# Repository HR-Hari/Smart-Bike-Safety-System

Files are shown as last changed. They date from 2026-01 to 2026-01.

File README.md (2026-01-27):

# Smart Bike Safety System

A **Smart Bike Safety System** for motor bikes using a **dual-microcontroller architecture**.  
The system detects theft attempts, abnormal movement, crash events, and **rider alcohol consumption**, sends **real-time alerts with GPS location** to the owner via **GSM**, and can **remotely disable the engine** for enhanced safety and security.

## Project Overview

Motor bike theft, unsafe riding, and delayed accident response remain major challenges.  
This project presents a **smart embedded safety and anti-theft solution** using **ESP32-based controllers**, inertial sensing, alcohol detection, GPS tracking, and GSM communication.

The system is divided into:

- **Master Unit (ESP32)** – Handles GPS tracking, GSM communication, crash detection, theft response, and engine cutoff.  
- **Slave Unit (ESP32-C3 Mini)** – Dedicated to rider safety monitoring, including alcohol detection and environmental sensing.

This modular design improves **reliability, power efficiency, fault isolation, and scalability**.

## System Functionality & Working

The Smart Bike Safety System operates using a **distributed dual-controller architecture** to ensure reliable monitoring and fast response. The **ESP32 Master unit**, powered directly from the bike battery, acts as the central control node responsible for decision-making, communication, and engine control. It interfaces with a **SIM900A GSM module** for SMS alerts, a **NEO-M8N GPS module** for real-time location tracking, a **5V relay** for engine cutoff, and an **MPU6050 inertial sensor** for detecting crash events and abnormal vehicle motion.

A secondary **ESP32-C3 Mini Slave unit**, powered by a rechargeable 5V battery, focuses on **rider safety monitoring**. It continuously measures alcohol concentration using the **MQ-3 alcohol sensor** and environmental conditions using the **DHT22 temperature and humidity sensor**. The Slave unit communicates safety status data wirelessly to the Master using **ESP-NOW**, enabling low-latency and power-efficient data transfer without relying on external networks.

During operation, the system continuously evaluates inputs from both controllers. If **alcohol consumption exceeds a predefined threshold**, a **crash is detected**, or **unauthorized movement** is identified, the Master unit immediately retrieves GPS coordinates and sends an **SMS alert via GSM** to the registered user. In critical scenarios, the system activates the **engine cutoff relay**, preventing the bike from being started or continuing operation. This integrated approach ensures **theft prevention, rider safety, and rapid incident notification** in a single embedded solution.

## Objectives

- Detect unauthorized movement or theft attempts  
- Detect crash events using inertial sensing  
- Detect rider alcohol consumption before or during riding  
- Send real-time SMS alerts with GPS location  
- Remotely disable the bike engine when unsafe conditions are detected  
- Implement a low-cost, embedded IoT-based safety system  

## System Architecture
            ┌────────────────────────────┐
            │        ESP32 MASTER        │
            │─────────────────────────── │
            │ • GSM (SIM900A)            │
            │ • GPS (NEO-M8N)            │
            │ • MPU6050 (Crash Detection)│
            │ • Engine Cutoff Relay      │
            │ • Alert & Control Logic    │
            └───────────▲────────────────┘
                        │ ESP-NOW
            ┌───────────┴────────────────┐
            │       ESP32-C3 MINI SLAVE  │
            │────────────────────────────│
            │ • MQ-3 (Alcohol Detection) │
            │ • DHT22 (Temp & Humidity)  │
            │ • Rider Safety Monitoring  │
            └────────────────────────────┘

## Hardware Components

### Master Unit (ESP32)

| Component | Description |
|---|---|
| ESP32 | Main controller |
| SIM900A GSM Module | SMS alert communication |
| NEO-M8N GPS Module | Real-time location tracking |
| MPU6050 | Crash and abnormal motion detection |
| 5V Relay Module | Engine cutoff control |
| Power Source | Motor bike 12V battery (regulated) |

### Slave Unit (ESP32-C3 Mini)

| Component | Description |
|---|---|
| ESP32-C3 Mini | Secondary controller |
| MQ-3 Alcohol Sensor | Rider alcohol detection |
| DHT22 | Temperature & humidity monitoring |
| Power Source | 5V rechargeable battery |

## Schematic

Schematic

## PCB & Enclosure Design

### Master Unit PCB Design
<table>
  <tr>
    <td>
      Master PCB
    </td>
    <td>
      Master 3D view
    </td>
  </tr>
</table>

### Slave Unit PCB Design

<table>
  <tr>
    <td>
      Slave PCB
    </td>
    <td>
      Slave 3D view
    </td>
  </tr>
</table>

### Master & Slave Enclosure / Casing

> **(Insert Master and Slave casing images here)**  
> *Show how the units are enclosed and protected for installation on the bike.*

## Software & Technologies

- **Programming Language**: C / C++
- **IDE**: Arduino IDE
- **Wireless Communication**:
  - ESP-NOW (ESP32 ↔ ESP32-C3)
- **Serial Communication**:
  - UART (ESP32 ↔ GSM)
  - UART (ESP32 ↔ GPS)
- **Core Concepts**:
  - Embedded Systems
  - IoT-based Vehicle Safety
  - Sensor Interfacing
  - Real-time Event Detection
  - Power Management

## Key Features

- Theft detection through abnormal motion analysis  
- Crash detection using MPU6050  
- Alcohol detection using MQ-3 sensor  
- Environmental monitoring using DHT22  
- GPS-based real-time location sharing  
- SMS alerts via GSM (SIM900A)  
- Engine immobilization using relay  
- Dual power supply for uninterrupted operation  

## Project Structure

## Testing & Validation

- Unauthorized movement and theft detection  
- Crash detection sensitivity tuning  
- Alcohol threshold calibration  
- GSM SMS delivery reliability  
- GPS fix accuracy and response time  
- Engine cutoff activation timing  

System validated under real motor bike operating conditions.

## Future Enhancements

- Mobile application integration  
- Cloud-based real-time tracking dashboard  
- Rider authentication using BLE or RFID  
- Geofencing alerts  
- AI-based rider behavior analysis

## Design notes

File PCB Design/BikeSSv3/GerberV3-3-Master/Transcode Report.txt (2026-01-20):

   ---- Transcoding 'D:\Uni\Semestter CS2\EE356\BikeSSv3\GerberV3-3-Master\BikeSSv3-Edge_Cuts.gbr' ----   Mon Nov 10 11:22:21 2025

D10   --> D100
-----------------------------------------------------------------

   ---- Transcoding 'D:\Uni\Semestter CS2\EE356\BikeSSv3\GerberV3-3-Master\BikeSSv3-F_Cu.gbr' ----   Mon Nov 10 11:22:21 2025

D34   --> D101
D35   --> D102
D36   --> D103
-----------------------------------------------------------------

   ---- Transcoding 'D:\Uni\Semestter CS2\EE356\BikeSSv3\GerberV3-3-Master\BikeSSv3-Edge_Cuts.gbr' ----   Wed Nov 12 11:34:07 2025

D10   --> D100
-----------------------------------------------------------------

   ---- Transcoding 'D:\Uni\Semestter CS2\EE356\BikeSSv3\GerberV3-3-Master\BikeSSv3-F_Cu.gbr' ----   Wed Nov 12 11:34:07 2025

D34   --> D101
D35   --> D102
D36   --> D103
-----------------------------------------------------------------

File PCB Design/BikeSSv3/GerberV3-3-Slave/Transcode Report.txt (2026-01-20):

   ---- Transcoding 'D:\Uni\Semestter CS2\EE356\BikeSSv3\GerberV3-3-Slave\BikeSSv3-Edge_Cuts.gbr' ----   Wed Nov 12 11:39:27 2025

D10   --> D100
-----------------------------------------------------------------

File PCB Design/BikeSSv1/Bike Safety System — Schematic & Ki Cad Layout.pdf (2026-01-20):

# Bike Safety System — Schematic & KiCad Layout

This document contains a complete, ready-to-follow schematic description, BOM, power-distribution and PCB layout guidance tailored for your bike safety/security system (ESP32 + NEO‑M8N + MPU6050 + optional GSM). Use this as the source-of-truth when creating the KiCad schematic and PCB.

## 1) Design goals (short)

Single 12 V input from bike. Robust input protection against reverse polarity and transients. Primary 5 V bus from a buck converter (automotive-capable) sized for bursts.
Clean 3.3 V rail (LDO) for ESP32 + IMU + GNSS (optionally use module breakout 5→3.3V if it has low-noise regulator).
Optional dedicated GSM power handling (large reservoir caps and/or dedicated regulator). Minimize switching noise coupling into GNSS/antenna and IMU.

## 2) High-level schematic (textual — map this directly into KiCad symbols)

Connectors

J1: BAT_IN — 2-pin screw terminal (VIN+, GND)
VIN+ → protection (reverse diode / MOSFET) → TVS → bulk cap → BUCK_IN
GND → system ground
J2: ANT_GPS — u.FL or SMA depending on antenna (connect to NEO-M8N ANT pad)
J3: USB_PROG — USB-C micro B as optional programming / serial power (connect via ideal-diode OR allow USB to power 5 V bus when present)
J4: OUTPUTS — Relay/Buzzer (open-drain via transistor)
J5: SIM_PWR — if using external SIM battery connector
Power block

D1 — Reverse-protection (Schottky or ideal diode MOSFET assembly). Example footprint: SOD-128 for Schottky or MOSFET SOT-23.
TVS1 — Automotive TVS (e.g., SMAJ58A or equivalent) across VIN after D1.
C_IN — Bulk electrolytic 220 µF — 1000 µF (low ESR) at VIN.
LDO1 — OPTIONAL: 5 V input soft-start or inrush limit circuit (NTC or small series resistor + MOSFET) if huge caps present.
BUCK1 — 12 V → 5.0 V buck converter. Rating: choose module/IC capable of continuous 3 A (or rated per your GSM/ESP peaks). Add LC filter at its output: ferrite bead F1 + L1 (10–47 µH) + C_OUT (100 µF electrolytic + 10 µF tantalum + 0.1 µF MLCC).
C_5V_local — 470 µF low-ESR on 5 V bus near distribution.

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
### 3.3 V domain

LDO3V3 — Low-noise LDO (e.g., TLV70033, MIC550, or similar). Input: 5 V bus after LC filter. Provide 10 µF + 0.1 µF close to LDO in/out.
C_3V3_local — 100 µF low-ESR + MLCCs near ESP32.
3.3 V net connects to: ESP32 VCC, MPU6050 VCC, (optionally) NEO‑M8N VCC if using direct 3.3 V rather than onboard regulator.
Highest-noise device (GSM)

If using SIM800L / BG95 / etc.: either create separate regulated 4 V rail or feed from 5 V bus but: Add C_GSM: 2200 µF–4700 µF low-ESR cap right at module power pins.
Add a series sense resistor or PFET disconnect and a polyfuse (resettable) so bursts don’t pull down system.
Place GSM power/antenna connectors at the board edge, physically separated from GNSS. Controller & sensors

U1: ESP32-WROOM (or WROVER if you need PSRAM) — 3.3 V VCC. Expose EN, IO0, TX0/RX0 for programming. Add 10 k pull-ups/pull-downs per reference schematic. Add decoupling: 100 nF + 10 µF.
U2: MPU6050 — I2C (SDA, SCL) to ESP32 I2C pins. Add 2.2 k pull-ups to 3.3 V if module lacks them. Decouple with 0.1 µF + 4.7 µF.
U3: NEO‑M8N (GNSS) — UART (TX/RX) to ESP32 Serial1 (use hardware serial). Also PPS pin optional to ESP32 GPIO. Power: 3.3 V is preferred. Antenna to J2. Decouple and add LC filter close to module: ferrite bead + 10 µF + 0.1 µF.
Misc

Level translators: not needed if all are 3.3 V. If any module is 5 V tolerant only (LCD), use level shifters.
Buzzer / Relay: NPN transistor (e.g., 2N2222 or SMD equivalent) with base resistor (10 k pull-down or 100 k?), flyback diode for coils, and emitter to GND. Drive from ESP32 GPIO through base resistor (4.7k).
LEDs: status LED with 4.7k series resistor.

## 3) BOM (suggested — verify footprints)

Ref | Part | Value / Notes | Qty
J1 | Screw terminal | 2-pin, 5.08 mm pitch | 1
D1 | Schottky | 40 V, SOD-128 | 1
TVS1 | TVS | 600 W, 58 V standoff or automotive-rated | 1
C_IN | Electrolytic | 470 µF, 25 V low-ESR | 1

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
Ref | Part | Value / Notes | Qty
BUCK1 | Buck module | 5 V, 3 A (module or integrated IC + inductor) | 1
L1 | Inductor | 10–47 µH (for LC) | 1
F1 | Ferrite bead | SMD ferrite (1206 or 0805) | 1
C_OUT | Electrolytic | 220 µF, 10 V low-ESR | 1
LDO3V3 | LDO | 3.3 V low-noise LDO, SOT-223 or SOT-23 | 1
C_3V3 | MLCC | 10 µF + 0.1 µF | 2
U1 | ESP32 module | WROOM or DEVKIT footprint | 1
U2 | MPU6050 | QFN breakout or module | 1
U3 | NEO‑M8N | GNSS breakout module | 1
U4 | SIM800L | if used | 1
Q1 | NPN | SOT-23 transistor for buzzer/relay | 1
Rb | Resistors | 4.7 k, 10 k etc | several

Note: exact package choices depend on your footprint preferences for soldering (hand-solder vs reflow). I recommend through-hole for connector/screw terminals and SMD for everything else.

## 4) PCB layout plan & rules (KiCad)

Layer stackup

2-layer board is fine for this project. Use:
Top: components, routing
Bottom: ground plane + routing
Recommend at least 35 µm copper (1 oz). If you expect >2 A continuous on some traces, consider 2 oz copper or heavier.
Placement priorities

Input protection & buck: place near J1 (VIN). Keep switching components local to minimize noise loops.
Bulk caps: place right at buck input & output.
GSM module: place at board edge, keep away from GNSS and ESP32 antenna path.
GNSS module & antenna: place on board corner/edge with a keep-out area around antenna. Keep it physically distant (≥30 mm ideally) from buck and GSM.
ESP32: central, but not next to buck or GSM. Keep its antenna clear (if module has antenna).
IMU: close to ESP32 to shorten I2C traces; avoid being next to switching loops.
Test pads & headers: program pins, 5 V, 3.3 V, GND, and serial lines.

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
Grounding

Use a continuous ground plane on bottom.
Route high-current return paths directly under their supply traces when possible so the plane carries return current.- Use stitching vias if you have localized ground islands.
Avoid splitting the ground plane under the GNSS antenna area.
Trace widths (conservative recommendations)

Use these conservative widths on 1 oz copper:
Signals (I2C, UART, GPIO): 0.25 mm (10 mil)
0.5 A traces: 0.8 mm
1 A traces: 1.5 mm
2 A traces: 2.5 mm
3 A traces: 3.0–3.5 mm
For the 5 V bus feeding multiple modules, use a wide plane or multiple 3.0 mm traces in parallel. Decoupling & filtering layout

Put MLCC 0.1 µF as close as possible to each IC Vcc pin.
Place larger electrolytic/tantalum caps near the module entry points.
Place ferrite bead + LC filter components in series with the 5 V feed to GNSS and ESP32 LDO input. Thermal & mechanical

If buck IC is in SMD, provide thermal vias under its pad connected to ground plane per datasheet. Keep mounting holes and mechanical pads clear of the antenna area.

## 5) KiCad project checklist (step-by-step)

Create new project in KiCad and set board units to mm.
Create schematic sheets: PWR, CONTROLLER, SENSORS, COMM, MECH.
Add symbols and annotate. Assign footprints (SOT-23, SOT-223, 0805, 1206, etc.). Add net labels: VIN, GND, 5V_BUS, 3V3, UART1_TX, UART1_RX, I2C_SDA, I2C_SCL, PPS. Run ERC and resolve warnings.
Generate netlist and import to PCBNew.
Place components following placement priorities above.
Create ground zone filled on bottom. Set thermal relief on through-hole pads. Route high-current tracks first (5 V, VIN, GND returns). Keep them short and wide. Add decoupling and testpoints. SILK notes for antenna keep-out and orientation. DRC and Gerber generation.

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
## 6) Testing & debug suggestions

Bring up the board with a current-limited bench supply and scope on the 5 V & 3.3 V rails. Watch for droops during ESP32 Wi-Fi TX and (if present) GSM bursts.
Verify GNSS fix stability with the antenna placed in intended mounting location before sealing the enclosure.
Check temperature of buck and LDO on continuous operation.
If you see jitter in GNSS, add more LC filtering or move buck further away.

## 7) Files & footprints I recommend creating in KiCad

Footprints: 2-pin screw terminal, u.FL, SOT-23 (D1), SOT-223 (LDO), 1206/0805 (passives), 3.3 V regulator SOT-23-5 for small LDOs.
Symbols: ESP32 module symbol with nets exposed (EN, IO0, IO2, GND, 3V3, TX0, RX0).

If you want, I can now: - produce a schematic PDF / SVG layout text that you can import or copy into KiCad, or - produce a detailed KiCad component placement and routing plan (with exact footprints and grid coordinates) for an assumed board size (e.g., 60×40 mm).

Tell me which of those two you want next and I will put it into the same canvas as a follow-up file.

•

•

•
•

•

•

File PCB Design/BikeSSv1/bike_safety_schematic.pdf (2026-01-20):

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

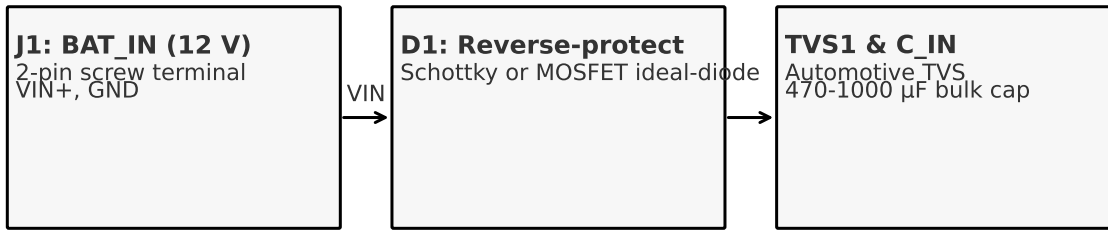
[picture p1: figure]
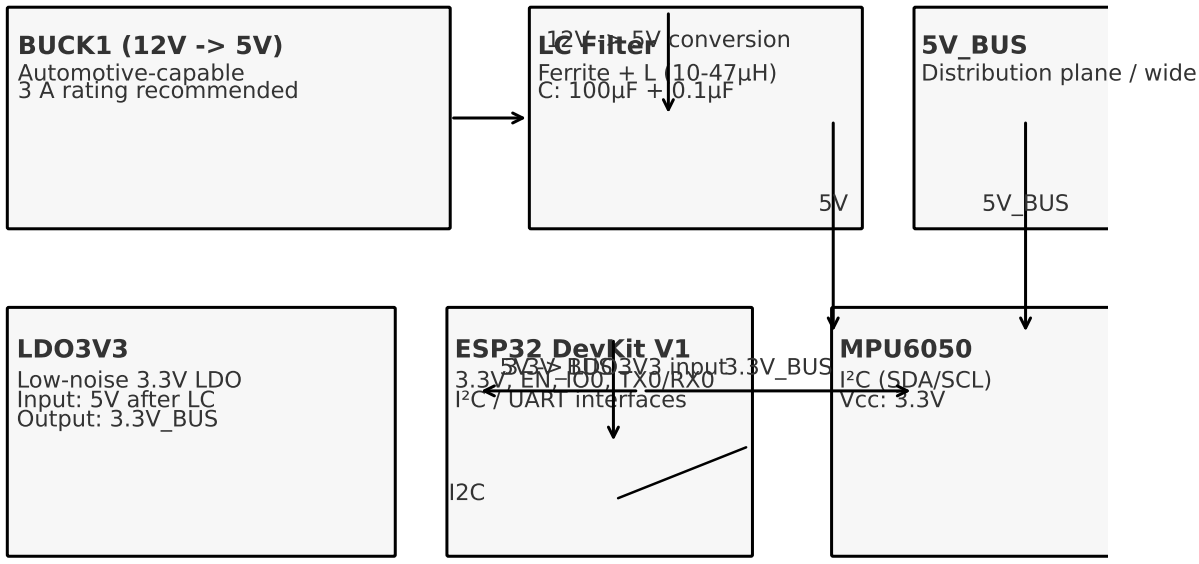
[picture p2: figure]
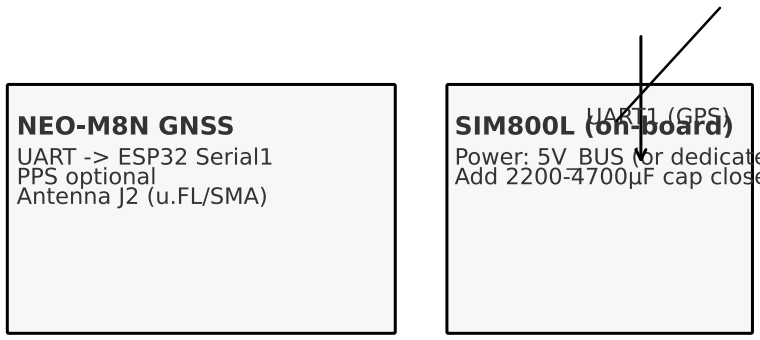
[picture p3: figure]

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

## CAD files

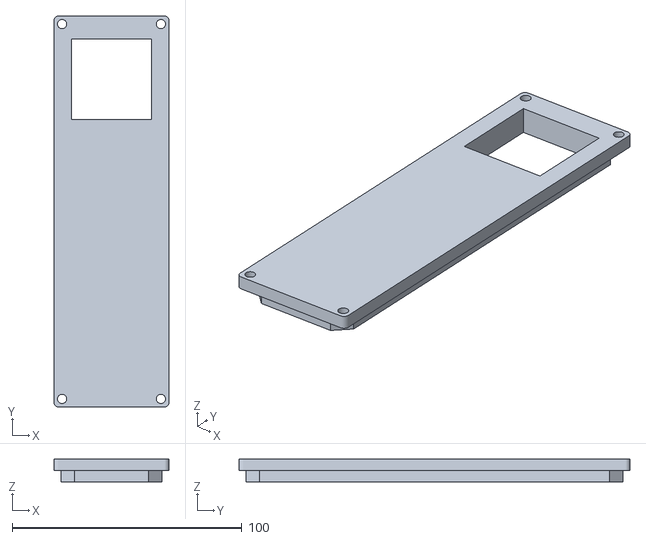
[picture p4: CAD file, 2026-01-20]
Casing/3D Print/Slave Enclosure-Lid.stl
50.0 x 170.0 x 10.0

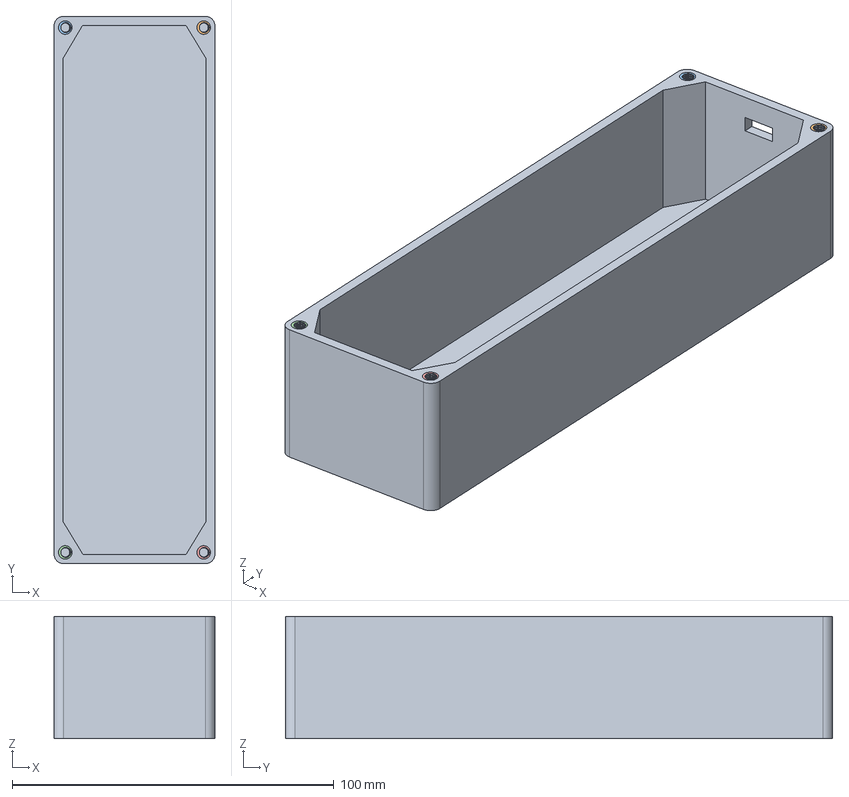
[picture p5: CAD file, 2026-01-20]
Casing/Master/Slave Big Enclosure.FCStd
50.0 x 170.0 x 38.0 mm
(M3.5)x13-ScrewDie003
(M3.5)x13-ScrewDie002
(M3.5)x13-ScrewDie001
(M3.5)x13-ScrewDie

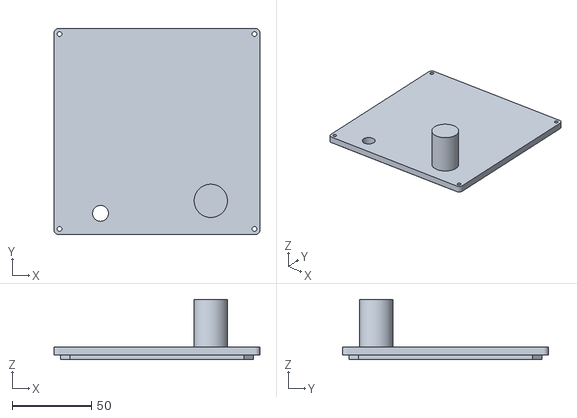
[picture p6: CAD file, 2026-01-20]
Casing/3D Print/Master Big_Enclosure-Lid -0.03.stl
130.0 x 130.0 x 38.0

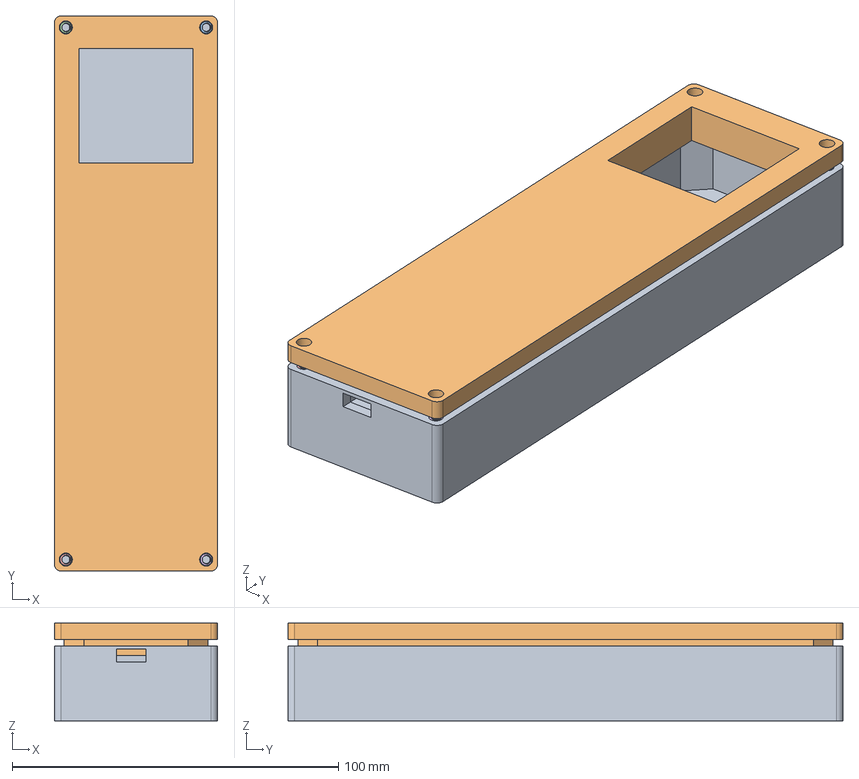
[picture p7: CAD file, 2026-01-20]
Casing/Master/Slave Enclosure.FCStd
50.0 x 170.0 x 30.0 mm
Container
Lid
M3x20-ScrewDie
M3x20-ScrewDie005
M3x20-ScrewDie004
M3x20-ScrewDie006

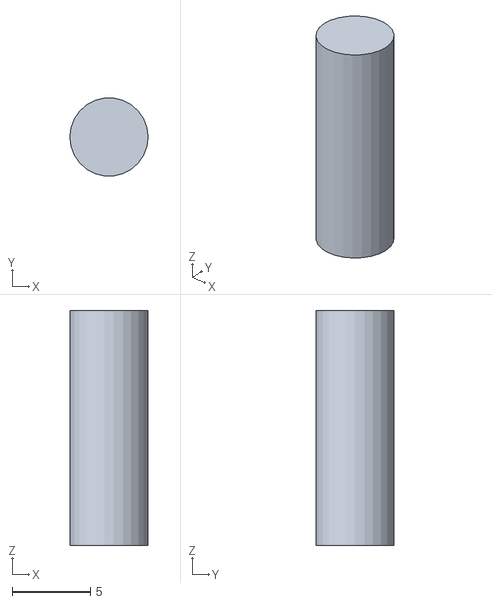
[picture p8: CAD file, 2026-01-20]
Casing/3D Print/Master Big_Enclosure-Switch.stl
5.00 x 4.96 x 15.0

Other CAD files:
Casing/3D Print/Slave Big Enclosure.stl
Casing/3D Print/Master Big_Enclosure-Lid -0.2.stl
Casing/3D Print/Master Big_Enclosure-Lid.stl

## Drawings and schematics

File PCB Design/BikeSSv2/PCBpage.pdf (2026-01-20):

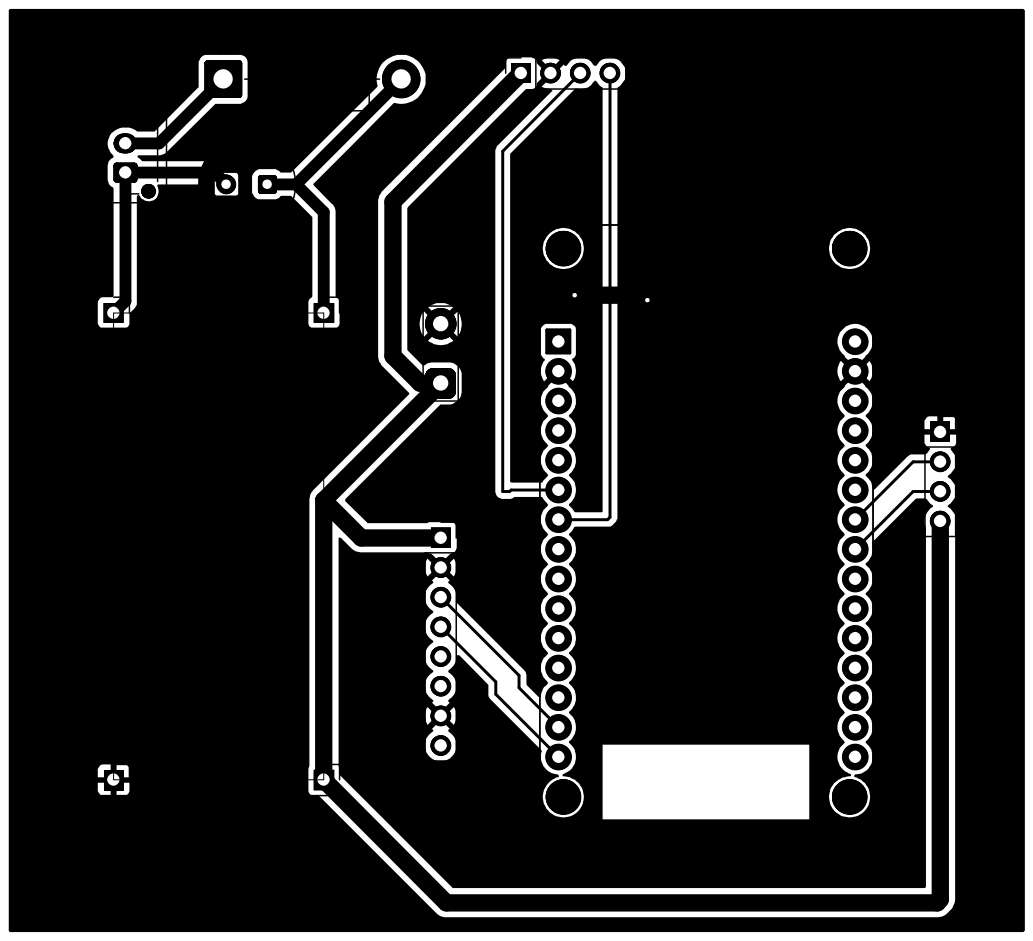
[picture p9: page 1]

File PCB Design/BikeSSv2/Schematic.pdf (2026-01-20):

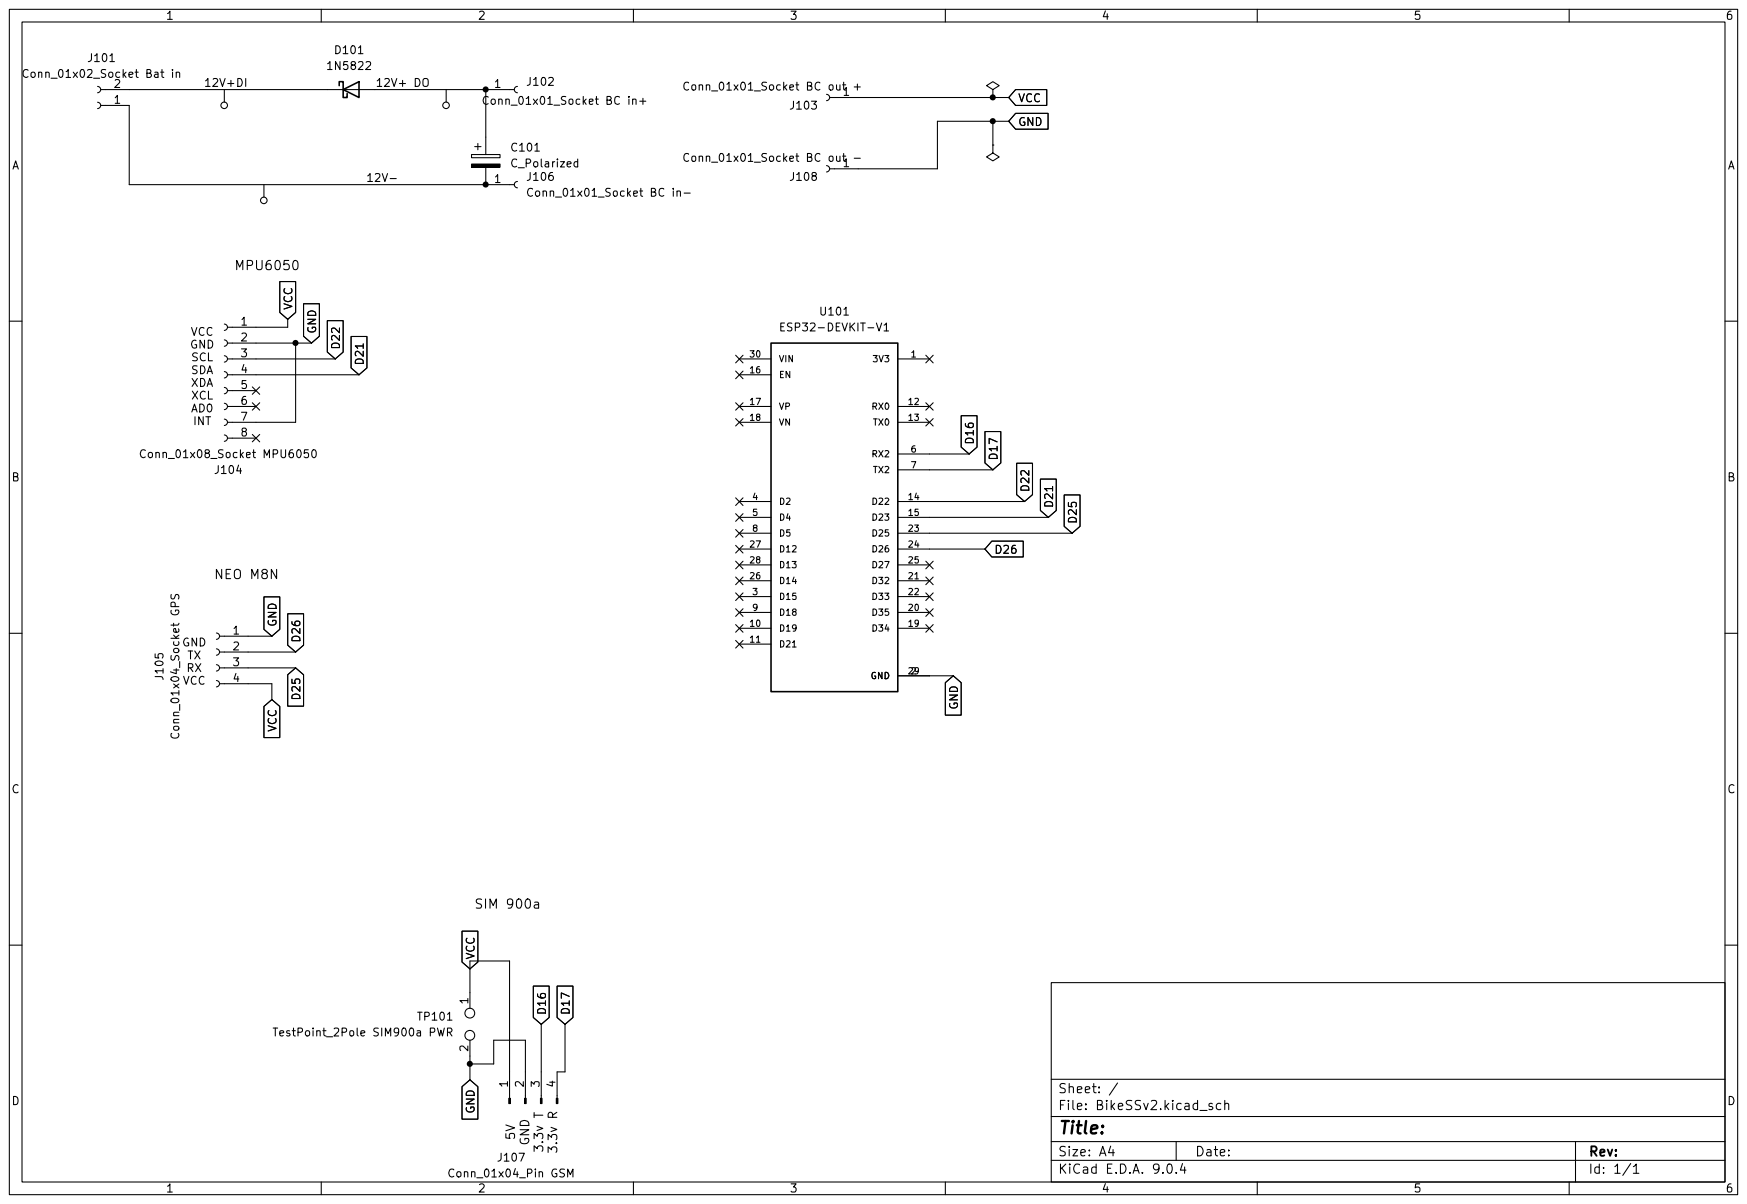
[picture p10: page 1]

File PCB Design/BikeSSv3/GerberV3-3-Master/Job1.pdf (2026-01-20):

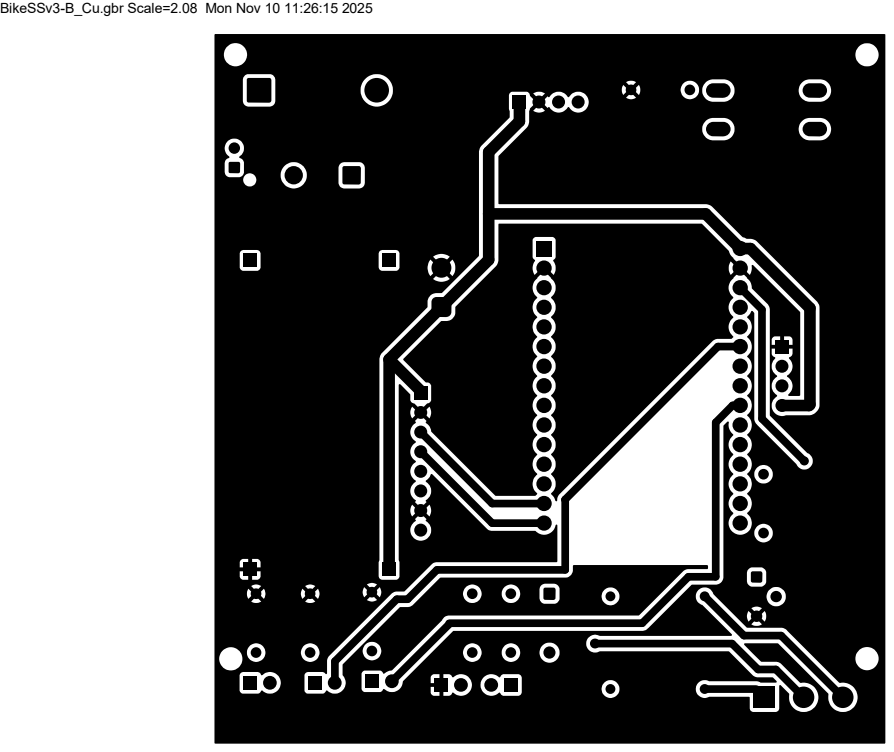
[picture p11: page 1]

BikeSSv3-B_Cu.gbr Scale=2.08 Mon Nov 10 11:26:15 2025

BikeSSv3-Edge_Cuts.gbr Scale=2.08 Mon Nov 10 11:26:15 2025

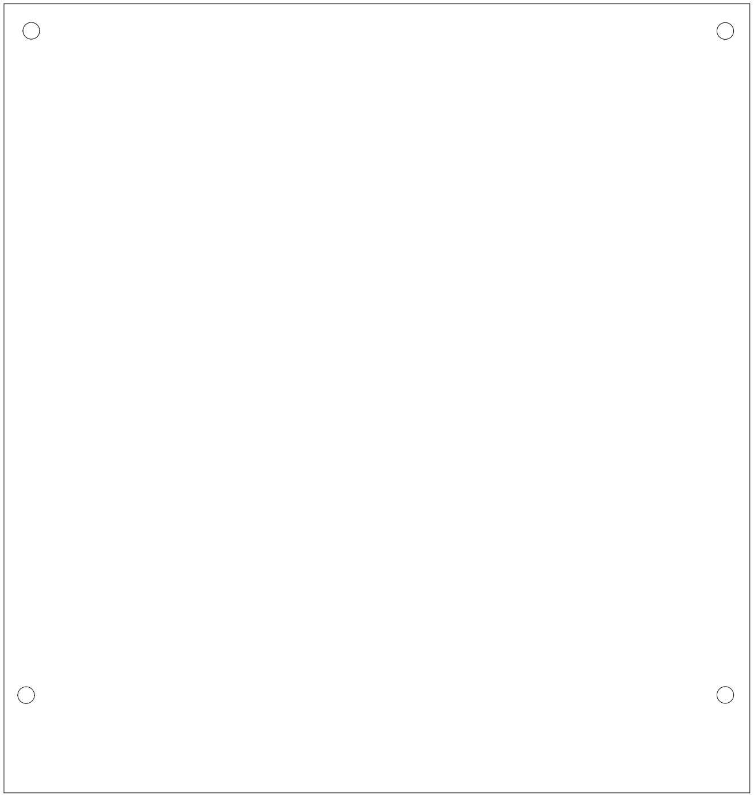
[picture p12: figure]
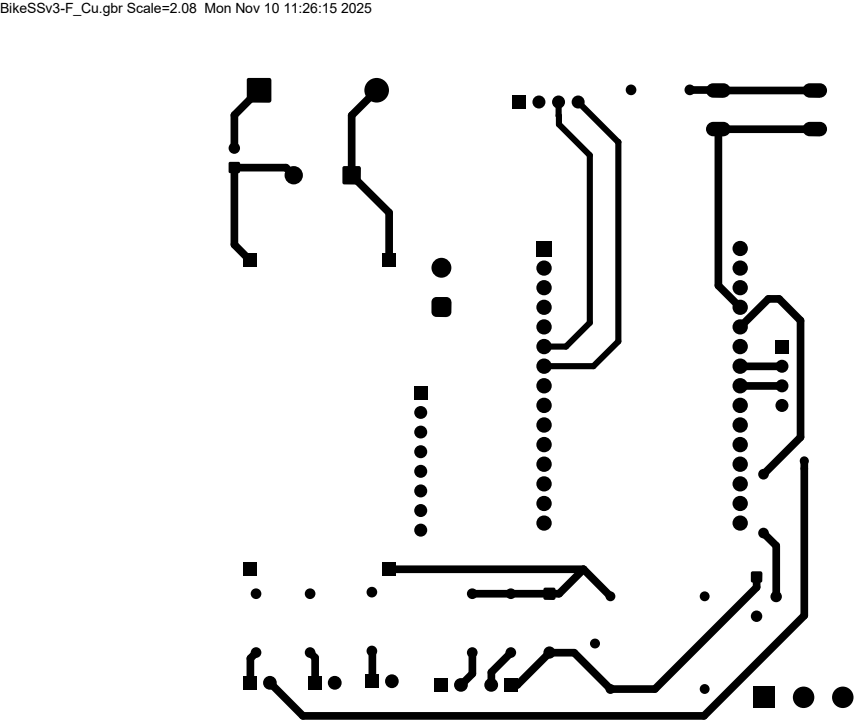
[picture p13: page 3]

BikeSSv3-F_Cu.gbr Scale=2.08 Mon Nov 10 11:26:15 2025

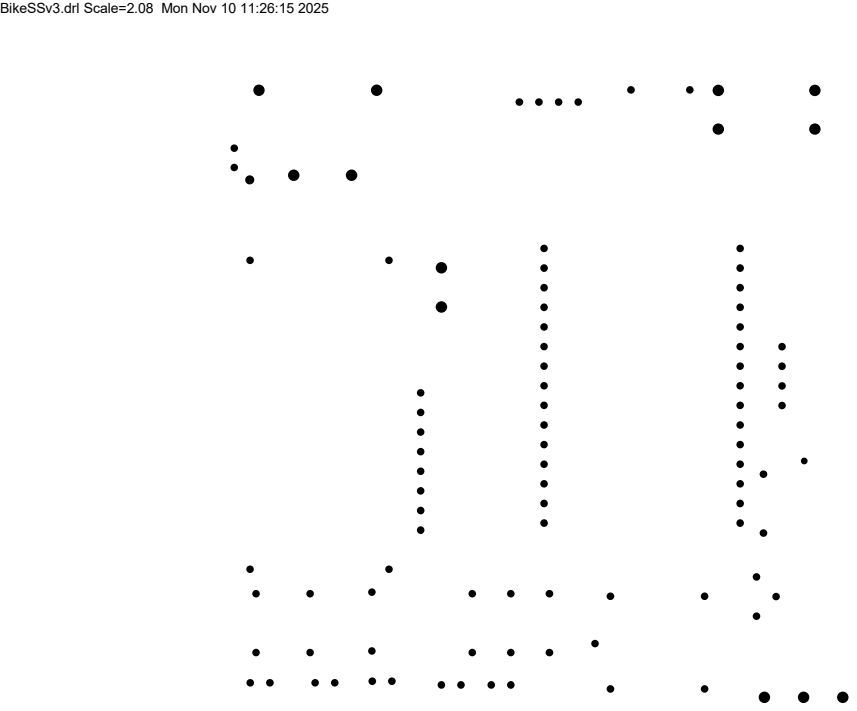
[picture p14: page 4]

BikeSSv3.drl Scale=2.08 Mon Nov 10 11:26:15 2025

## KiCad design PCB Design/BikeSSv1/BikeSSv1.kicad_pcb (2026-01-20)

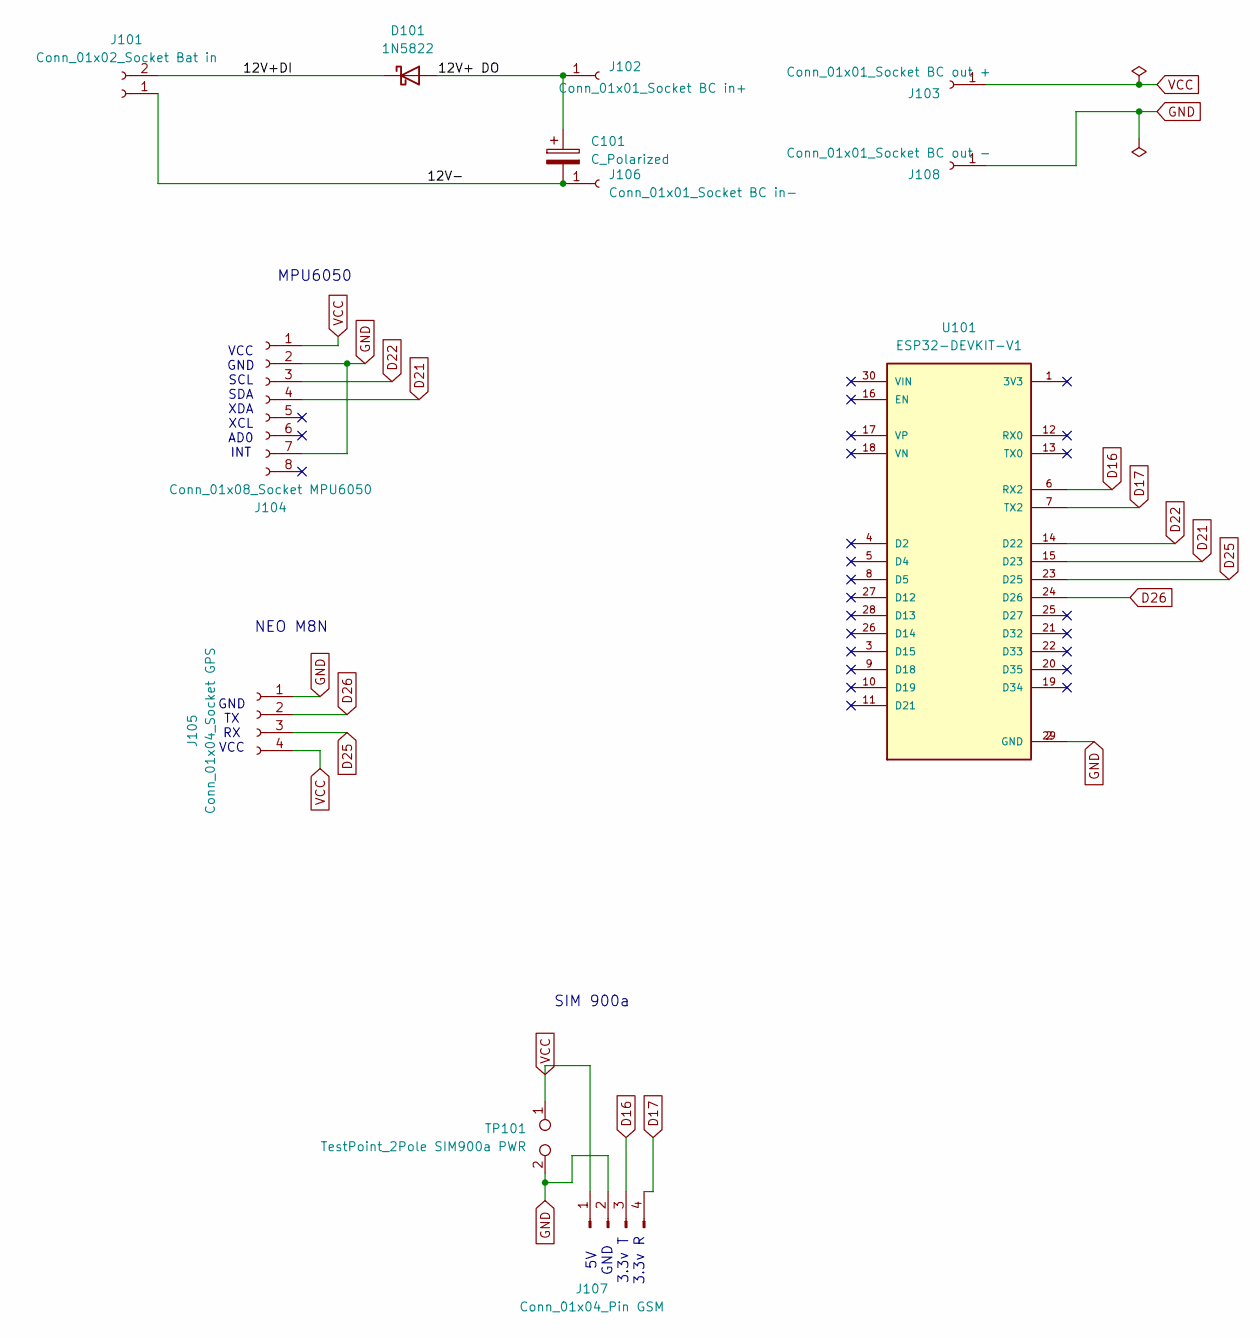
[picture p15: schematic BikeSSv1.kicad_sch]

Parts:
C101: C_Polarized; CP_Radial_D8.0mm_P3.50mm
D101: 1N5822; D_DO-201AD_P15.24mm_Horizontal
J101: Conn_01x02_Socket Bat in; JST_XH_B2B-XH-AM_1x02_P2.50mm_Vertical
J102: Conn_01x01_Socket BC in+; PinSocket_1x01_P2.54mm_Vertical
J103: Conn_01x01_Socket BC out +; PinSocket_1x01_P2.54mm_Vertical
J104: Conn_01x08_Socket MPU6050; PinSocket_1x08_P2.54mm_Vertical
J105: Conn_01x04_Socket GPS; PinSocket_1x04_P2.54mm_Vertical
J106: Conn_01x01_Socket BC in-; PinSocket_1x01_P2.54mm_Vertical
J107: Conn_01x04_Pin GSM; PinSocket_1x04_P2.54mm_Vertical
J108: Conn_01x01_Socket BC out -; PinSocket_1x01_P2.54mm_Vertical
TP101: TestPoint_2Pole SIM900a PWR; TestPoint_2Pads_Pitch5.08mm_Drill1.3mm
U101: ESP32-DEVKIT-V1; MODULE_ESP32_DEVKIT_V1; PARTREV N/A

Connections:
/12V+ DO: C101.1, D101.2 (A), J102.1
/12V+DI: D101.1 (K), J101.2
/12V-: C101.2, J101.1, J106.1
D16: J107.3, U101.6 (RX2)
D17: J107.4, U101.7 (TX2)
D21: J104.4, U101.15 (D23)
D22: J104.3, U101.14 (D22)
D25: J105.3, U101.23 (D25)
D26: J105.2, U101.24 (D26)
GND: J104.2, J104.7, J105.1, J107.2, J108.1, TP101.2, U101.2 (GND), U101.29 (GND)
VCC: J103.1, J104.1, J105.4, J107.1, TP101.1

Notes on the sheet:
VCC GND SCL SDA XDA XCL AD0 INT
5V GND 3.3v T 3.3v R
SIM 900a
NEO M8N
GND TX RX VCC
MPU6050

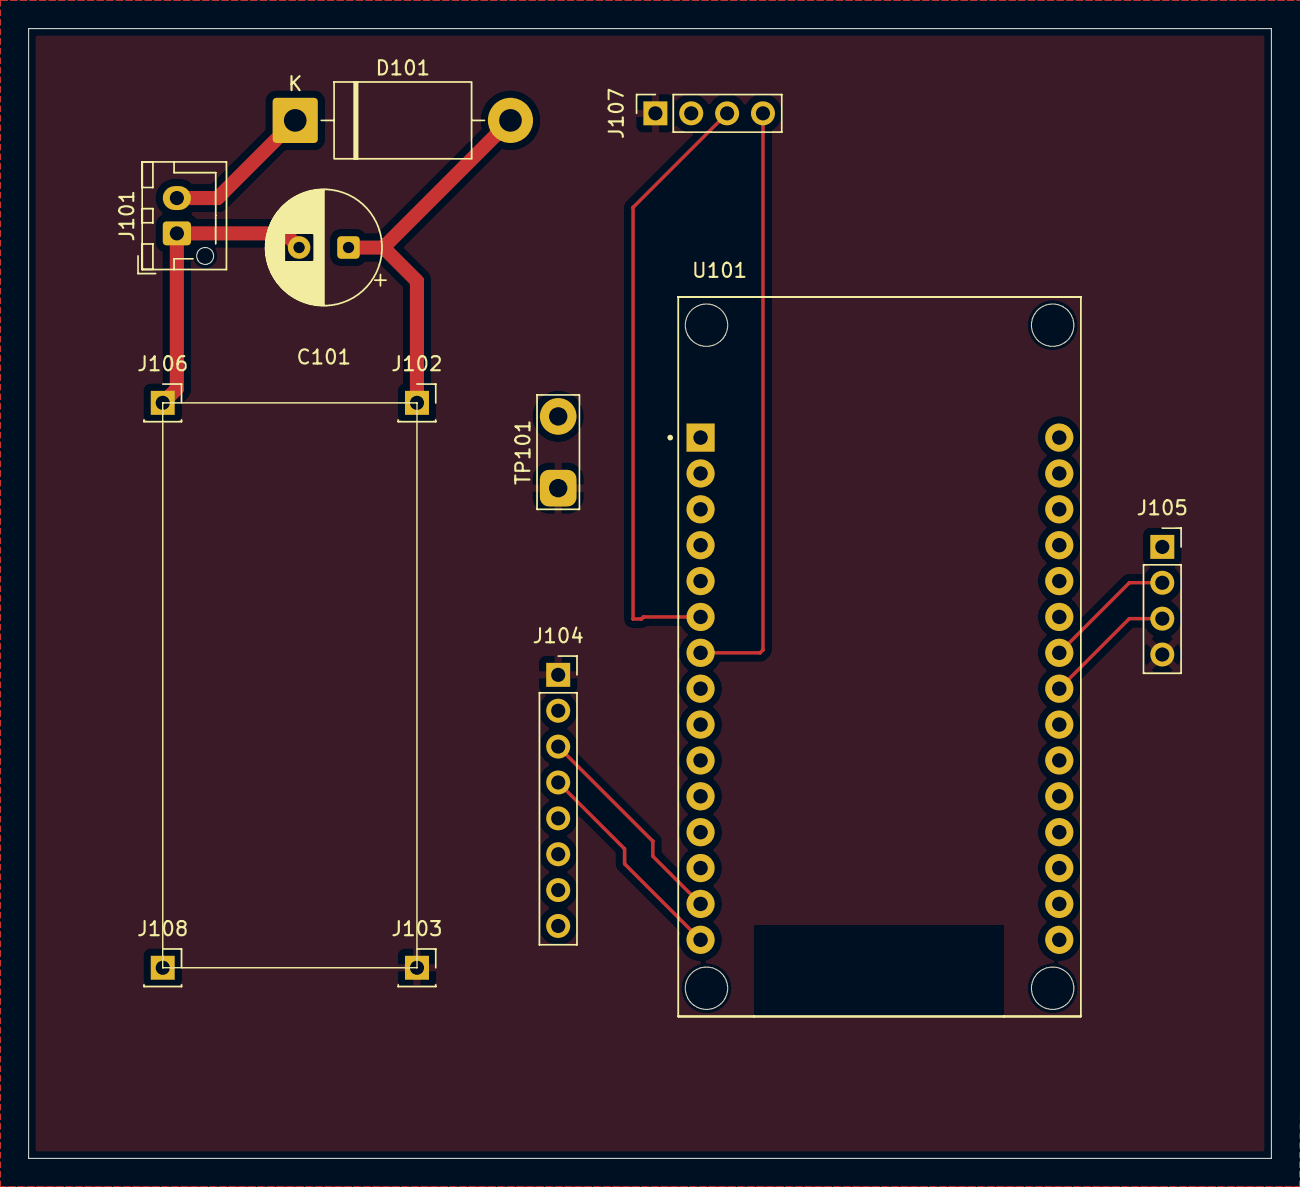
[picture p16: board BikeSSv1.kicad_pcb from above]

Board: 2 copper layers, 88.0 x 80.0 mm, 12 parts (0 on the bottom side), 11 nets.

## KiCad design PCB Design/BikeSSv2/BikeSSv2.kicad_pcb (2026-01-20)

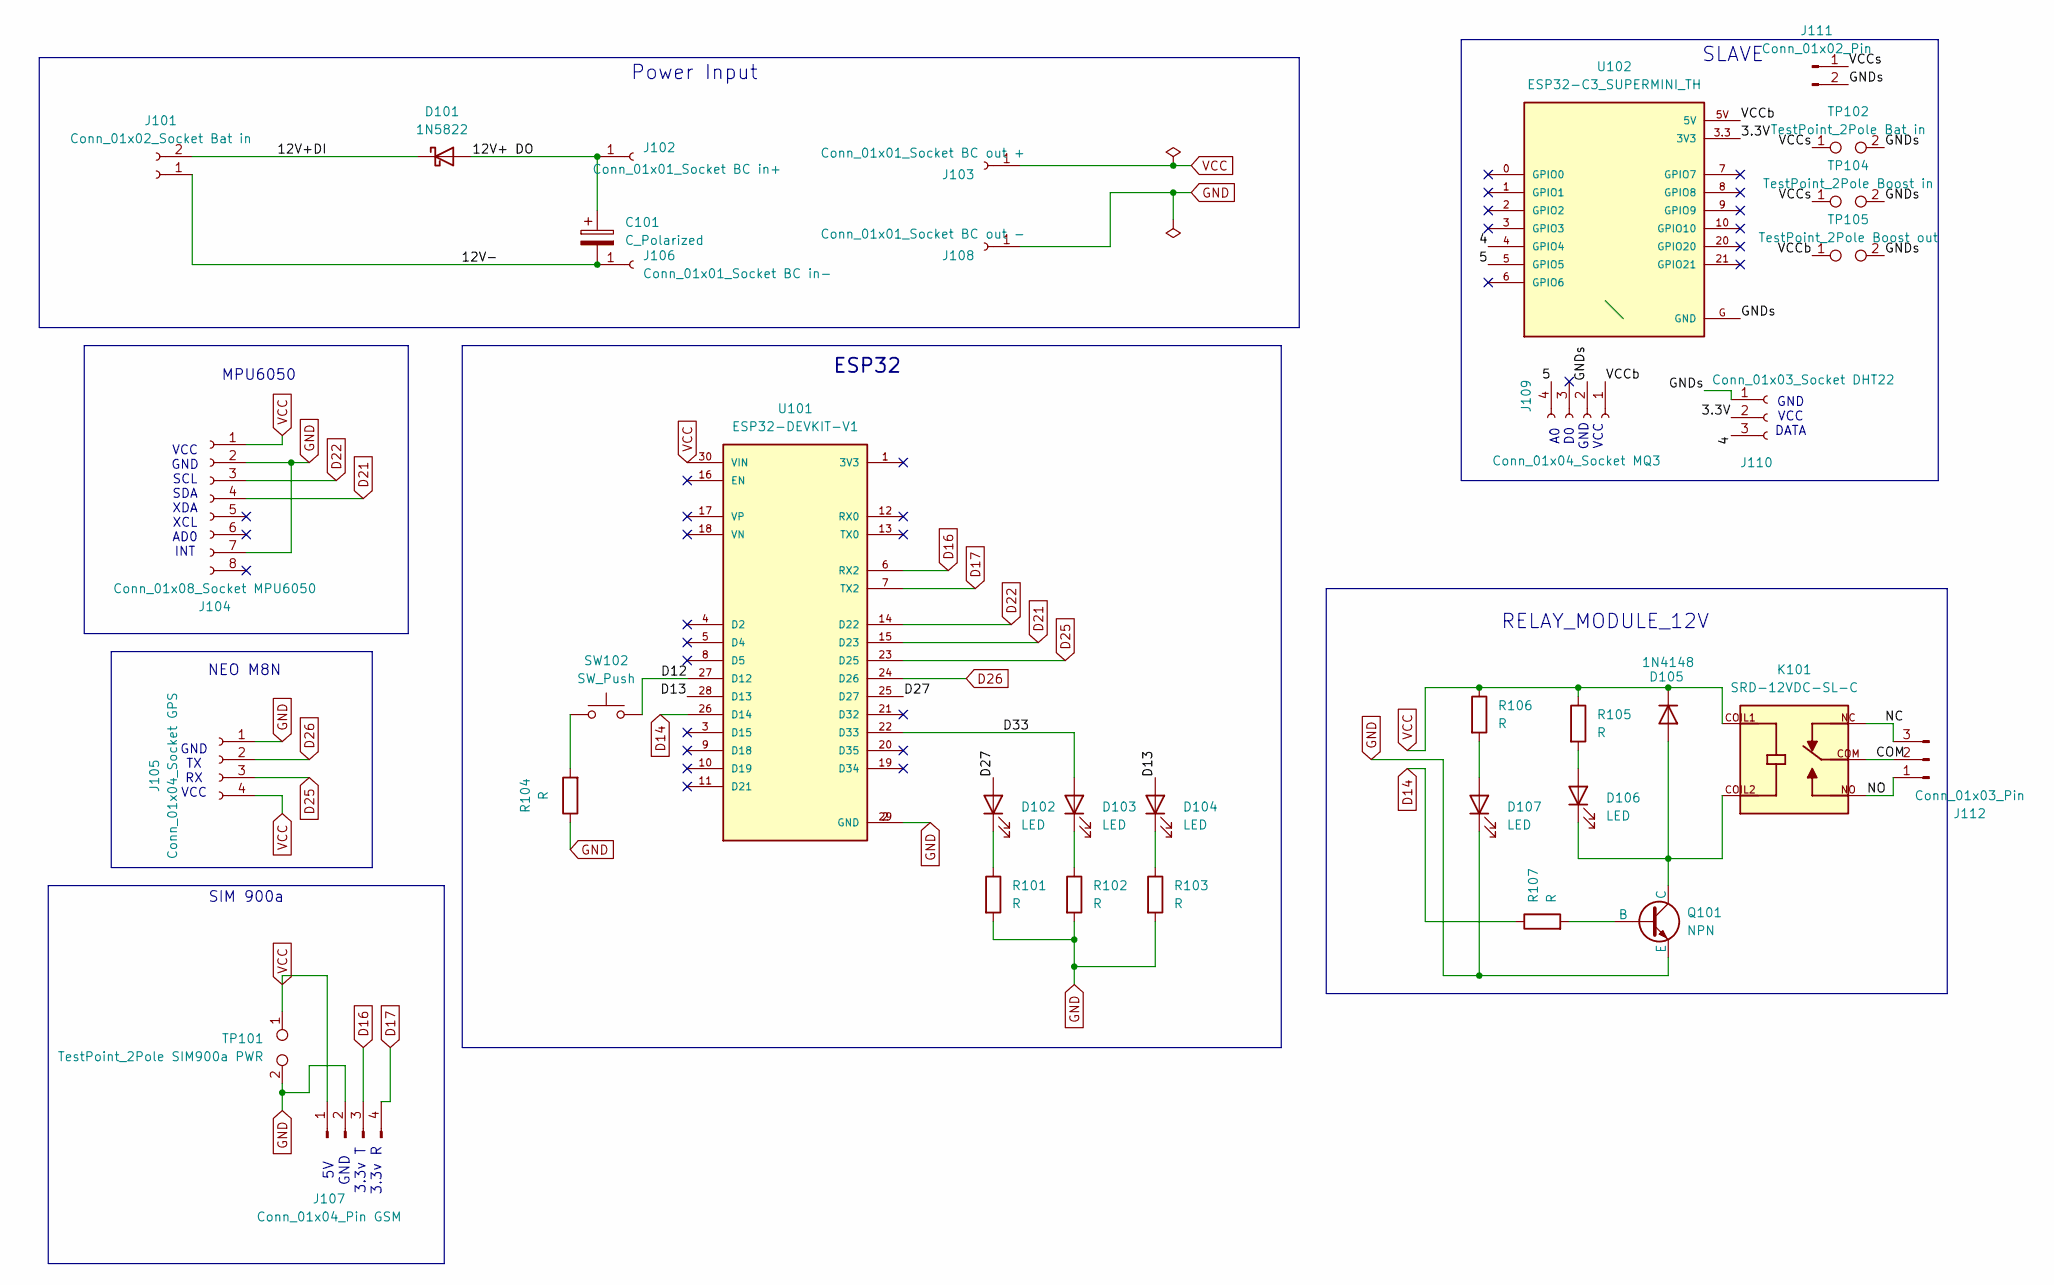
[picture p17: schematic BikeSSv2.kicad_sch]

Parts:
C101: C_Polarized; CP_Radial_D8.0mm_P3.50mm
D101: 1N5822; D_DO-201AD_P15.24mm_Horizontal
D102, D103, D104, D106, D107: LED; LED_D3.0mm_Clear
D105: 1N4148; D_DO-35_SOD27_P7.62mm_Horizontal
J101: Conn_01x02_Socket Bat in; JST_XH_B2B-XH-AM_1x02_P2.50mm_Vertical
J102: Conn_01x01_Socket BC in+; PinSocket_1x01_P2.54mm_Vertical
J103: Conn_01x01_Socket BC out +; PinSocket_1x01_P2.54mm_Vertical
J104: Conn_01x08_Socket MPU6050; PinSocket_1x08_P2.54mm_Vertical
J105: Conn_01x04_Socket GPS; PinSocket_1x04_P2.54mm_Vertical
J106: Conn_01x01_Socket BC in-; PinSocket_1x01_P2.54mm_Vertical
J107: Conn_01x04_Pin GSM; PinSocket_1x04_P2.54mm_Vertical
J108: Conn_01x01_Socket BC out -; PinSocket_1x01_P2.54mm_Vertical
J109: Conn_01x04_Socket MQ3; PinSocket_1x04_P2.54mm_Horizontal
J110: Conn_01x03_Socket DHT22; PinSocket_1x03_P2.54mm_Vertical
J111: Conn_01x02_Pin; JST_XH_S2B-XH-A-1_1x02_P2.50mm_Horizontal
J112: Conn_01x03_Pin; Samtec_HPM-03-05-x-S_Straight_1x03_Pitch5.08mm
K101: SRD-12VDC-SL-C; RELAY_SRD-12VDC-SL-C; PARTREV 1.0
Q101: NPN; TO-92L_Wide
R101, R102, R103, R104, R105, R106, R107: R; R_Axial_DIN0204_L3.6mm_D1.6mm_P7.62mm_Horizontal
SW102: SW_Push; SW_PUSH-12mm
TP101: TestPoint_2Pole SIM900a PWR; TestPoint_2Pads_Pitch5.08mm_Drill1.3mm
TP102: TestPoint_2Pole Bat in; Battery_Charger_TD4056_Module
TP104: TestPoint_2Pole Boost in; TestPoint_2Pads_Pitch7mm_Drill1.3mm
TP105: TestPoint_2Pole Boost out; TestPoint_2Pads_Pitch7mm_Drill1.3mm
U101: ESP32-DEVKIT-V1; MODULE_ESP32_DEVKIT_V1; PARTREV N/A
U102: ESP32-C3_SUPERMINI_TH; MODULE_ESP32-C3_SUPERMINI_TH

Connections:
/3.3V: J110.2, U102.3.3 (3V3)
/4: J110.3, U102.4 (GPIO4)
/5: J109.4, U102.5 (GPIO5)
/12V+ DO: C101.1, D101.2 (A), J102.1
/12V+DI: D101.1 (K), J101.2
/12V-: C101.2, J101.1, J106.1
/D12: SW102.2, U101.27 (D12)
/D13: D104.2 (A), U101.28 (D13)
/D27: D102.2 (A), U101.25 (D27)
/D33: D103.2 (A), U101.22 (D33)
/GNDs: J109.2, J110.1, J111.2, TP102.2, TP104.2, TP105.2, U102.G (GND)
/VCCb: J109.1, TP105.1, U102.5V
/VCCs: J111.1, TP102.1, TP104.1
D14: R107.1, U101.26 (D14)
D16: J107.3, U101.6 (RX2)
D17: J107.4, U101.7 (TX2)
D21: J104.4, U101.15 (D23)
D22: J104.3, U101.14 (D22)
D25: J105.3, U101.23 (D25)
D26: J105.2, U101.24 (D26)
GND: D107.1 (K), J104.2, J104.7, J105.1, J107.2, J108.1, Q101.3 (E), R101.2, R102.2, R103.2, R104.1, TP101.2, U101.2 (GND), U101.29 (GND)
unnamed: D102.1 (K), R101.1
unnamed: D103.1 (K), R102.1
unnamed: D104.1 (K), R103.1
unnamed: D105.2 (A), D106.1 (K), K101.COIL2, Q101.1 (C)
unnamed: D106.2 (A), R105.2
unnamed: D107.2 (A), R106.2
unnamed: J112.1, K101.NO
unnamed: J112.2, K101.COM
unnamed: J112.3, K101.NC
unnamed: Q101.2 (B), R107.2
unnamed: R104.2, SW102.1
VCC: D105.1 (K), J103.1, J104.1, J105.4, J107.1, K101.COIL1, R105.1, R106.1, TP101.1, U101.30 (VIN)

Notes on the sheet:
SLAVE
A0 D0 GND VCC
VCC GND SCL SDA XDA XCL AD0 INT
RELAY_MODULE_12V
ESP32
5V GND 3.3v T 3.3v R
SIM 900a
NEO M8N
GND TX RX VCC
GND VCC DATA
Power Input
MPU6050

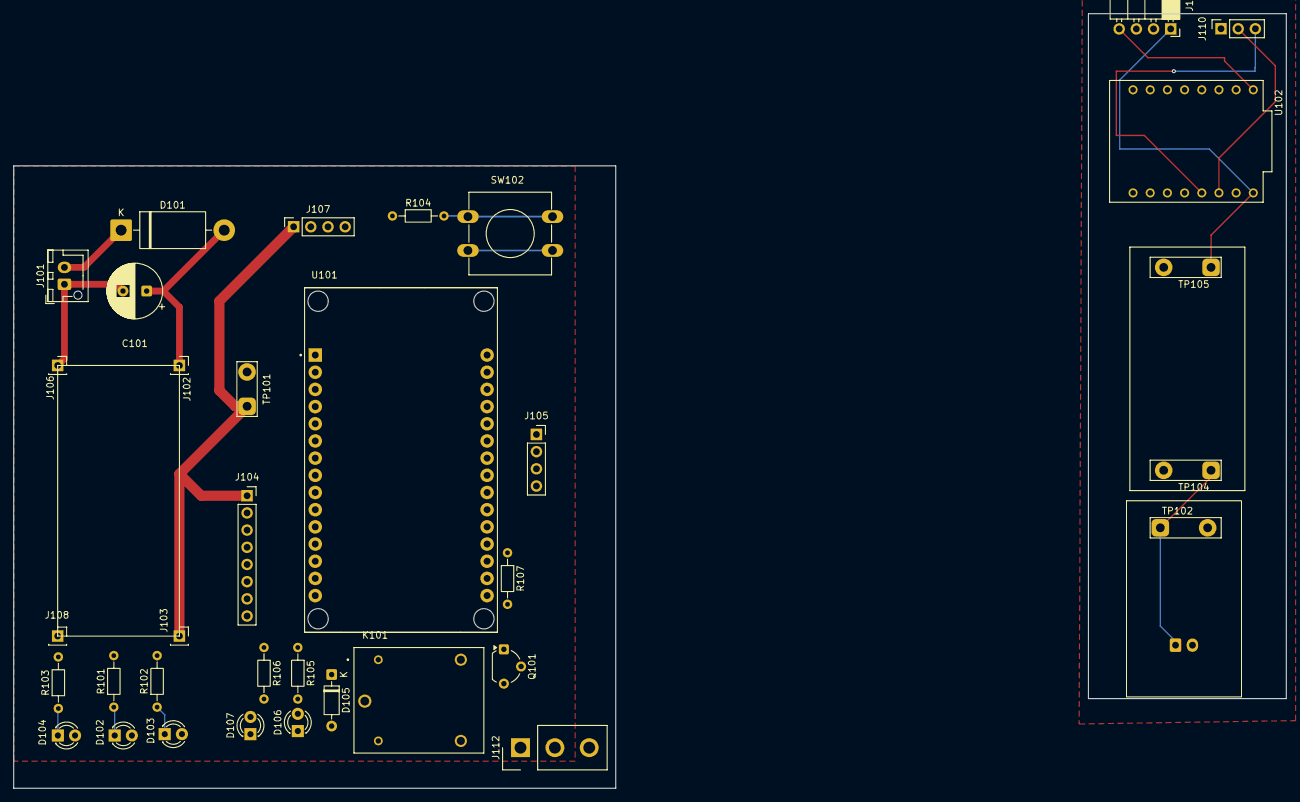
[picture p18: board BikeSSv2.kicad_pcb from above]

Board: 2 copper layers, 89.0 x 92.0 mm, 36 parts (1 on the bottom side), 33 nets.

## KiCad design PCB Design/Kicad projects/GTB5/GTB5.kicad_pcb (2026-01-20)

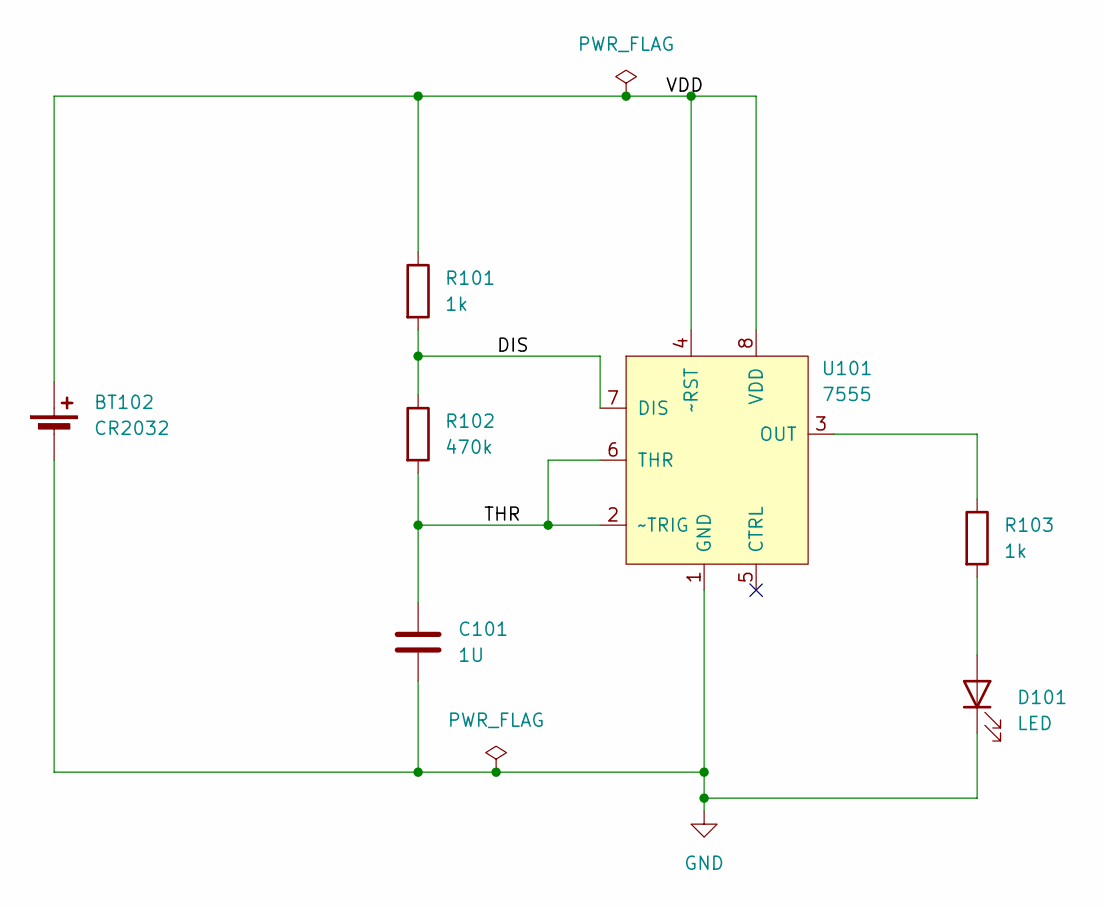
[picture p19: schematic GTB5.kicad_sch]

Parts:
BT102: CR2032; S8211-46R
C101: 1U; C_0805_2012Metric_Pad1.18x1.45mm_HandSolder
D101: LED; LED_0805_2012Metric_Pad1.15x1.40mm_HandSolder
R101, R103: 1k; R_0805_2012Metric_Pad1.20x1.40mm_HandSolder
R102: 470k; R_0805_2012Metric_Pad1.20x1.40mm_HandSolder
U101: 7555; SOIC-8_3.9x4.9mm_P1.27mm

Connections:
/DIS: R101.2, R102.1, U101.7 (DIS)
/THR: C101.1, R102.2, U101.2 (~TRIG), U101.6 (THR)
/VDD: BT102.1 (+), R101.1, U101.4 (~RST), U101.8 (VDD)
GND: BT102.2 (-), C101.2, D101.1 (K), U101.1 (GND)
unnamed: D101.2 (A), R103.2
unnamed: R103.1, U101.3 (OUT)

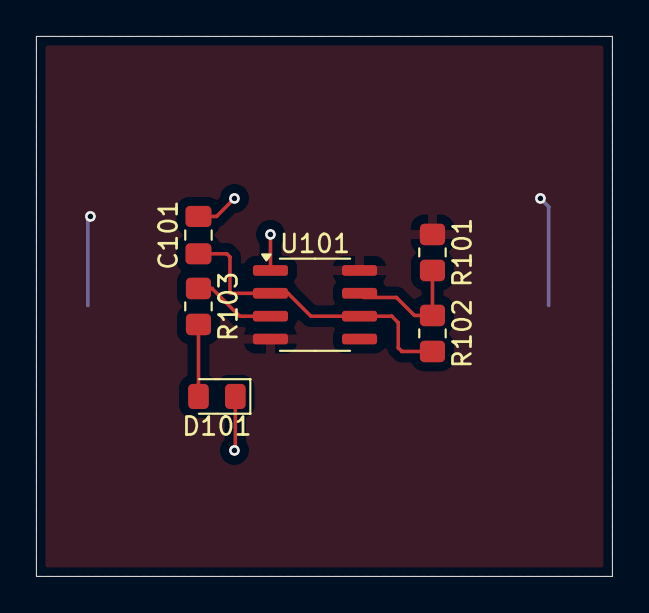
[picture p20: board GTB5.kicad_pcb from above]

Board: 2 copper layers, 32.0 x 30.0 mm, 7 parts (1 on the bottom side), 6 nets.

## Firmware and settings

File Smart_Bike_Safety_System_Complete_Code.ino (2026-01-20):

#include <Wire.h>
#include <WiFi.h>
#include <esp_now.h>
#include <TinyGPSPlus.h>
#include "MPU6050.h"

/* ================= PIN DEFINITIONS ================= */
#define GSM_RX 16        // ESP32 RX ← SIM900A TX
#define GSM_TX 17        // ESP32 TX → SIM900A RX

#define LED_CRASH 13     // ON for 5 seconds when crash detected
#define LED_GPS   27     // ON when GPS lock
#define LED_GSM   33     // ON when GSM registered



/* ================= OBJECTS ================= */
HardwareSerial gsmSerial(2);
TinyGPSPlus gps;
MPU6050 mpu;

/* ================= DATA STRUCTURES ================= */
typedef struct {
  bool alcoholDetected;
} AlcoholData;

AlcoholData alcoholData;

/* ================= VARIABLES ================= */
unsigned long crashLedTimer = 0;
bool crashLedActive = false;

/* ================= FUNCTION DECLARATIONS ================= */
void sendCrashSMS(const String &msg);
bool detectCrash();

/* ================= ESP-NOW CALLBACK (FIXED) ================= */
void OnDataRecv(const esp_now_recv_info *info,
                const uint8_t *incomingData,
                int len) {

  memcpy(&alcoholData, incomingData, sizeof(alcoholData));

  if (alcoholData.alcoholDetected) {
    String msg = "ALERT: Alcohol detected.\n";

    if (gps.location.isValid()) {
      msg += "Location:\nhttps://www.google.com/maps?q=";
      msg += String(gps.location.lat(), 6);
      msg += ",";
      msg += String(gps.location.lng(), 6);
    } else {
      msg += "GPS not fixed.";
    }

    sendCrashSMS(msg);
  }
}

/* ================= SETUP ================= */
void setup() {
  Serial.begin(115200);

  pinMode(LED_CRASH, OUTPUT);
  pinMode(LED_GPS, OUTPUT);
  pinMode(LED_GSM, OUTPUT);

  digitalWrite(LED_CRASH, LOW);
  digitalWrite(LED_GPS, LOW);
  digitalWrite(LED_GSM, LOW);

  /* ---------- I2C + MPU6050 FIRST ---------- */
  Wire.begin(23,22);
  mpu.initialize();

  if (!mpu.testConnection()) {
    Serial.println("MPU6050 connection failed");
    while (1);
  }
  Serial.println("MPU6050 ready");

  /* ---------- GSM ---------- */
  gsmSerial.begin(9600, SERIAL_8N1, GSM_RX, GSM_TX);
  delay(3000);

  gsmSerial.println("AT");
  delay(1000);
  gsmSerial.println("AT+CMGF=1");   // SMS text mode
  delay(1000);

  /* ---------- GPS (UART0 passthrough assumed externally) ---------- */
  Serial.println("Waiting for GPS fix...");

  /* ---------- ESP-NOW ---------- */
  WiFi.mode(WIFI_STA);

  if (esp_now_init() != ESP_OK) {
    Serial.println("ESP-NOW init failed");
    while (1);
  }

  esp_now_register_recv_cb(OnDataRecv);

  Serial.println("ESP-NOW ready");
}

/* ================= LOOP ================= */
void loop() {

  /* ---------- GPS STATUS ---------- */
  while (Serial.available()) {
    gps.encode(Serial.read());
  }

  if (gps.location.isValid()) {
    digitalWrite(LED_GPS, HIGH);
  } else {
    digitalWrite(LED_GPS, LOW);
  }

  /* ---------- GSM NETWORK STATUS ---------- */
  gsmSerial.println("AT+CREG?");
  delay(200);

  if (gsmSerial.find(",1") || gsmSerial.find(",5")) {
    digitalWrite(LED_GSM, HIGH);
  } else {
    digitalWrite(LED_GSM, LOW);
  }

  /* ---------- CRASH DETECTION ---------- */
  if (detectCrash()) {
    digitalWrite(LED_CRASH, HIGH);
    crashLedTimer = millis();
    crashLedActive = true;

    String msg = "CRASH DETECTED!\n";
    if (gps.location.isValid()) {
      msg += "Location:\nhttps://www.google.com/maps?q=";
      msg += String(gps.location.lat(), 6);
      msg += ",";
      msg += String(gps.location.lng(), 6);
    }

    sendCrashSMS(msg);
  }

  /* ---------- CRASH LED AUTO OFF (5s) ---------- */
  if (crashLedActive && millis() - crashLedTimer >= 5000) {
    digitalWrite(LED_CRASH, LOW);
    crashLedActive = false;
  }

  delay(500);
}

/* ================= FUNCTIONS ================= */

bool detectCrash() {
  int16_t ax, ay, az;
  mpu.getAcceleration(&ax, &ay, &az);

  float magnitude = sqrt(ax * ax + ay * ay + az * az) / 16384.0;

  return (magnitude > 3.0);  // tuned crash threshold
}

void sendCrashSMS(const String &msg) {
  gsmSerial.println("AT+CMGS=\"+94782009028\"");  // replace number
  delay(500);
  gsmSerial.print(msg);
  delay(500);
  gsmSerial.write(26); // CTRL+Z
  delay(3000);
}
